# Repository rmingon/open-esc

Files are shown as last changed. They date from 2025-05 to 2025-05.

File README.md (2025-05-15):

# Open-Source 3-Phase Sensorless ESC Firmware

This is an open-source firmware for controlling 3-phase sensorless BLDC motors using an ATmega88PA microcontroller running at 8 MHz (internal oscillator).  
It is designed for small electric vehicles, drones, robotics, and DIY ESC applications.  
The design uses 6 MOSFETs in a three-phase bridge configuration and includes back-EMF sensing for sensorless commutation.

---

## Features

- Sensorless 6-step (trapezoidal) commutation
- Automatic open-loop startup
- Zero-cross detection via ADC ISR
- Hardware timer-based phase PWM with dead-time
- RC PWM input for speed control
- Optional serial interface (UART) for speed setting
- Direction control and braking support
- Dead-time insertion to prevent MOSFET shoot-through
- Auto-calibrated ADC thresholds for zero-cross detection

---

## Schematic Overview

The system includes the following main blocks:

### Microcontroller

- **ATmega88PA**, powered at 5V using AMS1117-3.3 regulator from +BATT
- Internal 8 MHz oscillator (no external crystal)
- Key pins used:
  - `PD2` → PWM input (from RC receiver)
  - `PD3/PD4/PD5` → High-side MOSFET gates (AH, BH, CH)
  - `PB0/PB1/PB2` → Low-side PWM outputs (AL, BL, CL)
  - `PC0/PC1/PC2` → ADC inputs for Phase A/B/C sensing (A0, A1, A2)

### Power Stage

- 3-phase half-bridge using 6 MOSFETs (Q1–Q6)
- High-side: A03401A
- Low-side: IRLML0030
- Gate resistors to control switching speed and prevent ringing

### Back-EMF Sensing

- Analog divider + DC blocking on each motor phase
- Inputs go to `A0`, `A1`, and `A2`
- Used for zero-cross detection in closed-loop mode

### PWM Input

- Connected to `D2` for RC signal input (standard 1–2 ms pulses)
- Used to control speed and direction
- Interrupt-based decoding for accurate readings

### Serial Debug (optional)

- Via UART (TX/RX, `PD0`/`PD1`)
- Can be used to override speed or monitor state

---

## How to Use

### 1. Assemble the Hardware

- Follow the schematic to build the ESC on a PCB or breadboard
- Ensure proper power filtering (C2, C3–C6)
- Use heatsinks or airflow on the MOSFETs if under heavy load

### 2. Upload Firmware

- Connect AVR ISP programmer to the 6-pin header
- Use [AVRDude](https://www.nongnu.org/avrdude/) or the Arduino IDE
- Ensure fuse bits are set for:
  - Internal 8 MHz clock
  - No clock division
- Upload the `.ino` firmware file

### 3. Calibrate Zero-Crossing (Auto)

- When powered, the firmware automatically calibrates ADC offset thresholds
- Ensure the motor is disconnected or not rotating for accurate calibration

### 4. Run

- Connect an RC receiver or PWM generator to `D2`
- Pulse width controls speed and direction:
  - `< 1480 µs` = reverse
  - `1480–1520 µs` = brake
  - `> 1520 µs` = forward
- Motor will spin up in open-loop mode and switch to sensorless control

### 5. Serial Control (Optional)

- Connect USB-to-serial to TX/RX
- Open serial monitor at `115200 baud`
- Send a value from `0–255` to manually set the speed (for testing/debug)

---

## Motor Braking and Reverse

- Controlled by PWM signal:
  - Brake mode: both high and low sides turned off briefly
  - Reverse: same commutation order but in reverse
- No position feedback required

---

## Dead-Time Handling

- Implemented in software by carefully disabling/enabling high/low MOSFETs with a short delay (a few µs)
- Prevents simultaneous conduction and shoot-through

---

## Files Included

- `ESC_Firmware.ino` – Full firmware with PWM control, ISR ADC, RC interface
- `README.md` – Project documentation
- Schematic (`.png`) – Visual hardware design

---

## Supported Microcontrollers

- ATmega88PA (default)
- Can be ported to ATmega328P with minimal changes

---

## Test Points

- TP1–TP3: Phase voltages for probing/debug
- TP6: PWM input
- TP5: GND
- TP4: +BATT

---

## Pictures

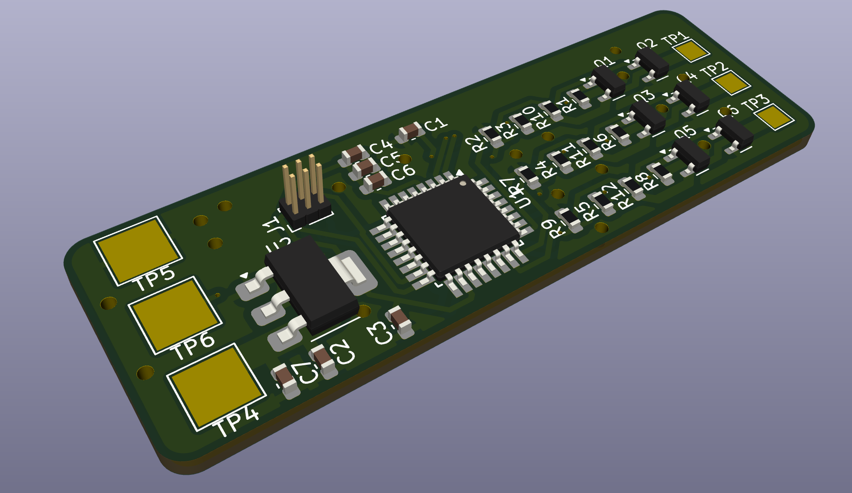
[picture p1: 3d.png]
3d

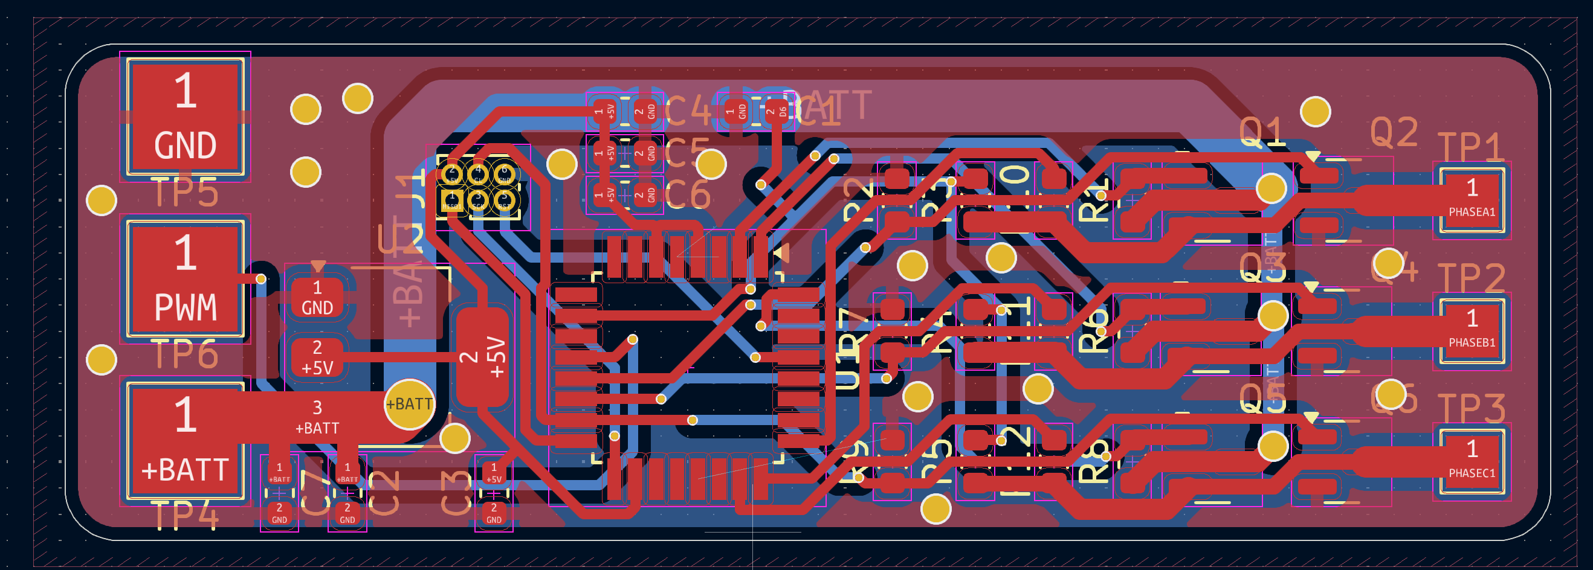
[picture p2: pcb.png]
pcb

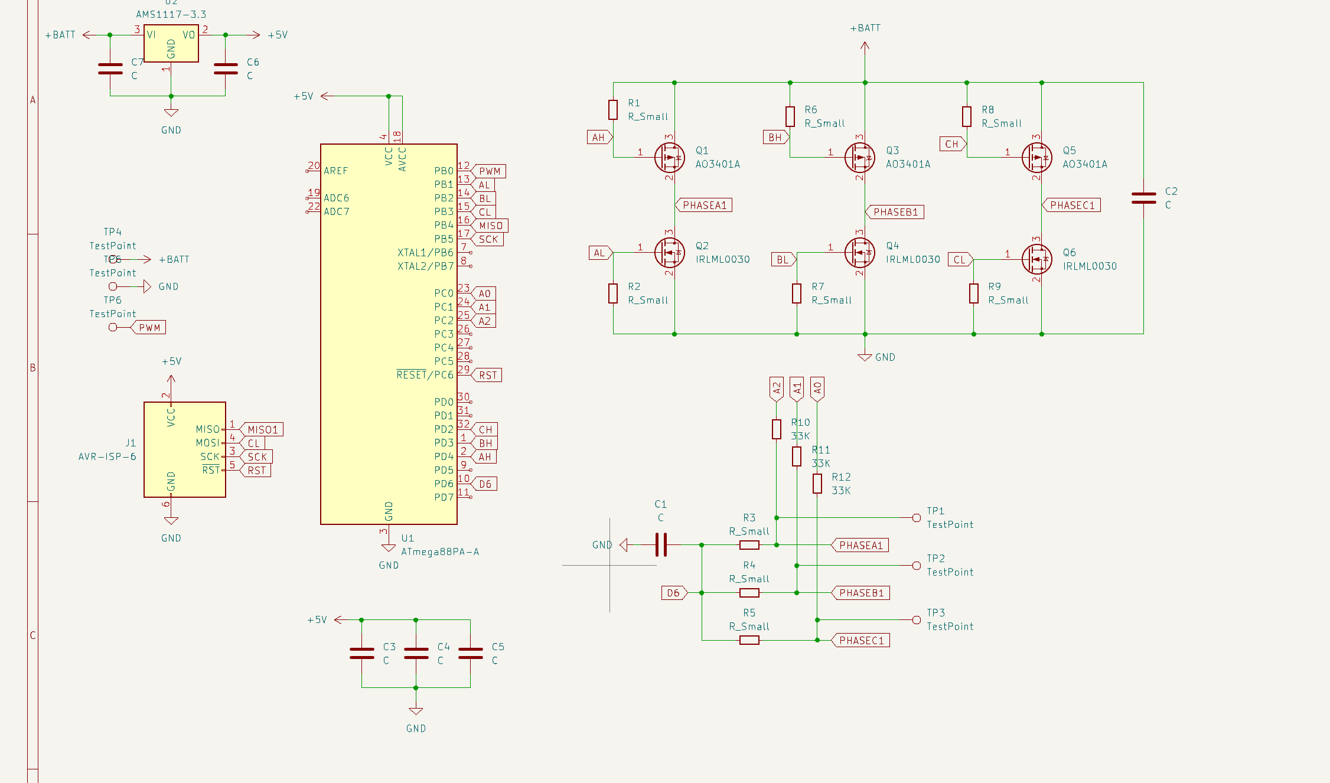
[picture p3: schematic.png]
schematic


---

## Safety Notes

- Always test with low-voltage supply first
- Double-check gate drive signals with oscilloscope
- Use overcurrent and overtemperature protection externally if needed

---

## License

MIT License — You can freely use, modify, and distribute this project.

---

## Author

Created by [Your Name / GitHub Handle]  
Feel free to fork, improve, and contribute via pull requests!

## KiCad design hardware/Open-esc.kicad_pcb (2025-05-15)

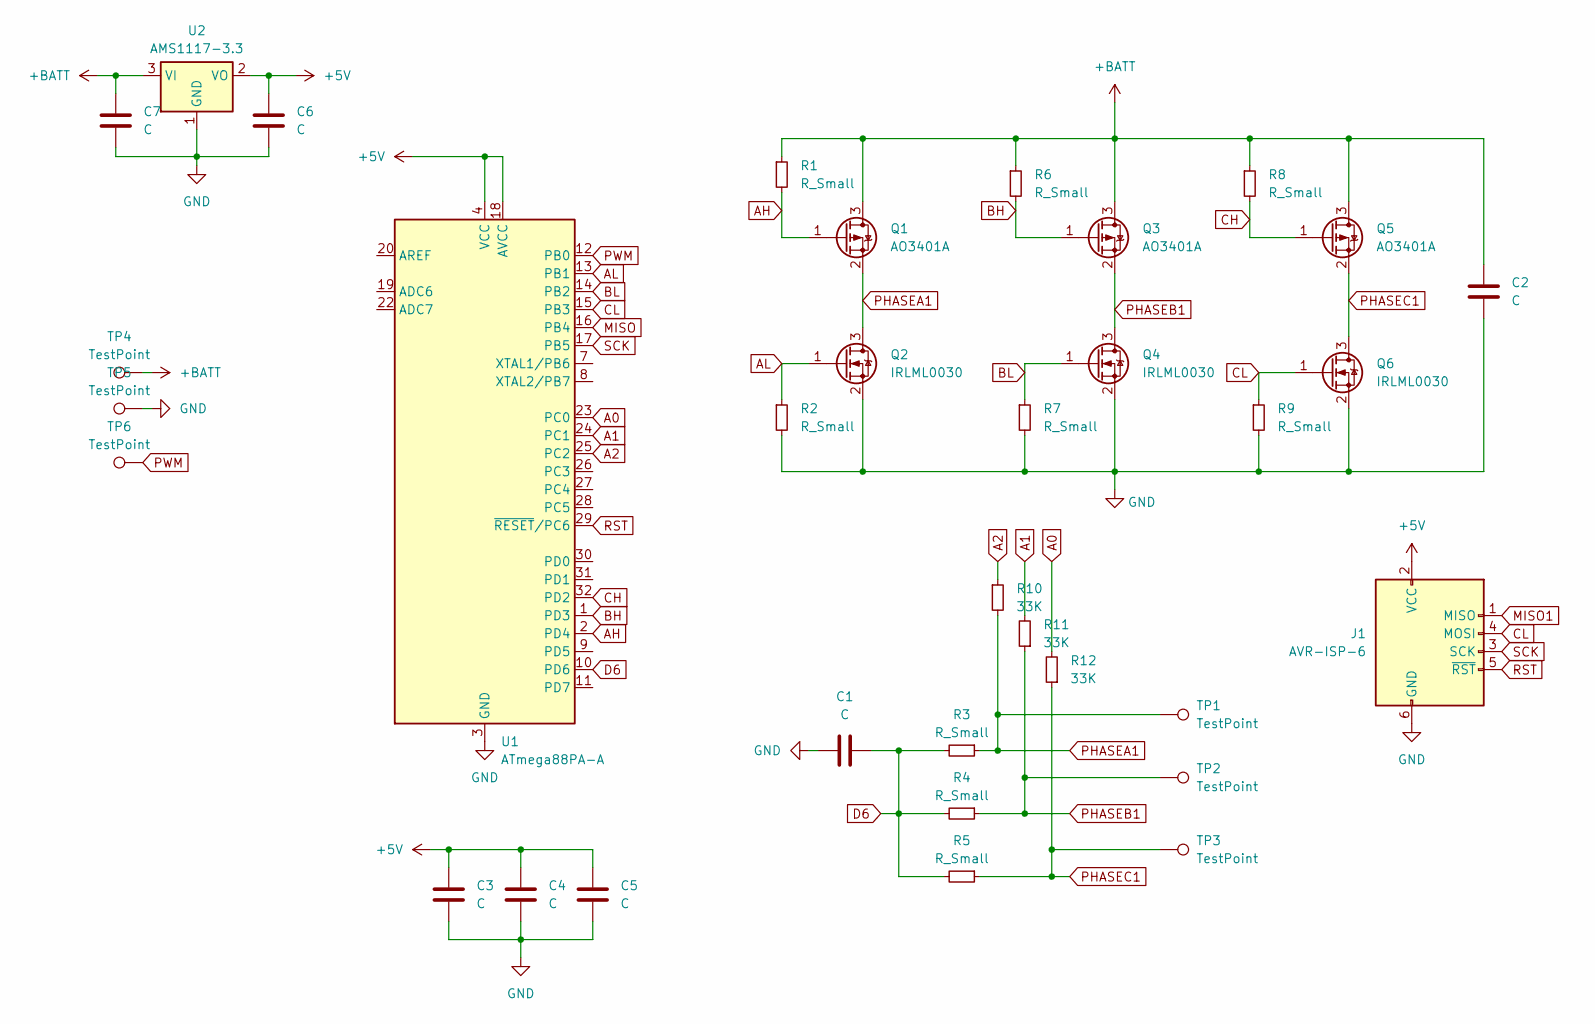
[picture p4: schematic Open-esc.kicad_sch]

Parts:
C1, C2, C3, C4, C5, C6, C7: C; C_0603_1608Metric
J1: AVR-ISP-6; PinHeader_2x03_P1.00mm_Vertical
Q1, Q3, Q5: AO3401A; SOT-23
Q2, Q4, Q6: IRLML0030; SOT-23
R1, R2, R3, R4, R5, R6, R7, R8, R9: R_Small; R_0603_1608Metric
R10, R11, R12: 33K; R_0603_1608Metric
TP1, TP2, TP3: TestPoint; TestPoint_Pad_2.0x2.0mm
TP4, TP5, TP6: TestPoint; TestPoint_Pad_4.0x4.0mm
U1: ATmega88PA-A; TQFP-32_7x7mm_P0.8mm
U2: AMS1117-3.3; SOT-223-3_TabPin2

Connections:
+5V: C3.1, C4.1, C5.1, C6.1, J1.2 (VCC), U1.4 (VCC), U1.6 (VCC), U1.18 (AVCC), U2.2 (VO)
+BATT: C2.1, C7.1, Q1.3 (D), Q3.3 (D), Q5.3 (D), R1.1, R6.1, R8.1, TP4.1, U2.3 (VI)
A0: R12.2, U1.23 (PC0)
A1: R11.2, U1.24 (PC1)
A2: R10.1, U1.25 (PC2)
AH: Q1.1 (G), R1.2, U1.2 (PD4)
AL: Q2.1 (G), R2.1, U1.13 (PB1)
BH: Q3.1 (G), R6.2, U1.1 (PD3)
BL: Q4.1 (G), R7.1, U1.14 (PB2)
CH: Q5.1 (G), R8.2, U1.32 (PD2)
CL: J1.4 (MOSI), Q6.1 (G), R9.1, U1.15 (PB3)
D6: C1.2, R3.2, R4.2, R5.2, U1.10 (PD6)
GND: C1.1, C2.2, C3.2, C4.2, C5.2, C6.2, C7.2, J1.6 (GND), Q2.2 (S), Q4.2 (S), Q6.2 (S), R2.2, R7.2, R9.2, TP5.1, U1.3 (GND), U1.5 (GND), U1.21 (GND), U2.1 (GND)
MISO: U1.16 (PB4)
MISO1: J1.1 (MISO)
PHASEA1: Q1.2 (S), Q2.3 (D), R3.1, R10.2, TP1.1
PHASEB1: Q3.2 (S), Q4.3 (D), R4.1, R11.1, TP2.1
PHASEC1: Q5.2 (S), Q6.3 (D), R5.1, R12.1, TP3.1
PWM: TP6.1, U1.12 (PB0)
RST: J1.5 (~RST), U1.29 (~RESET/PC6)
SCK: J1.3 (SCK), U1.17 (PB5)

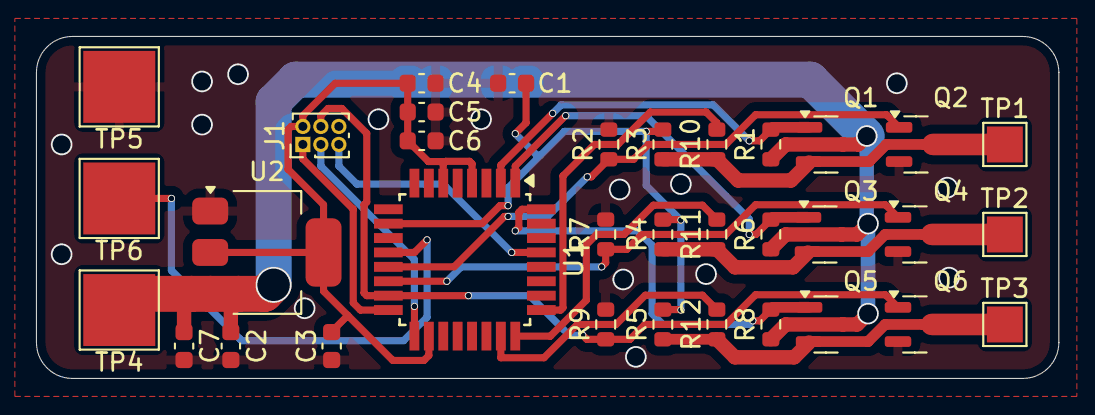
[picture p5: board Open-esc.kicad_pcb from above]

Board: 2 copper layers, 56.8 x 19.0 mm, 34 parts (0 on the bottom side), 19 nets.

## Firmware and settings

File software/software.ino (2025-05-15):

#define AH_PIN 8
#define BH_PIN 7
#define CH_PIN 6

#define AL_PIN 9
#define BL_PIN 10
#define CL_PIN 11

#define PHASE_A_ADC A2
#define PHASE_B_ADC A1
#define PHASE_C_ADC A0

#define PWM_INPUT_PIN 2  // RC-style PWM input (1–2 ms pulse)

const int8_t commutation_table[6][3] = {
  {1, 0, -1}, {1, -1, 0}, {0, 1, -1},
  {-1, 1, 0}, {0, -1, 1}, {-1, 0, 1}
};

volatile uint8_t step = 0;
volatile bool closedLoop = false;
volatile uint16_t dutyCycle = 0;
volatile uint16_t targetDutyCycle = 128;
volatile unsigned long lastStepTime = 0;
volatile unsigned int commutationDelay = 2000;
volatile bool zeroCrossDetected = false;
volatile int16_t lastADCValue = 512;
int8_t direction = 1;

uint16_t zeroCrossThresholdA = 512;
uint16_t zeroCrossThresholdB = 512;
uint16_t zeroCrossThresholdC = 512;
bool calibrationDone = false;

volatile unsigned long pwmRiseTime = 0;
volatile uint16_t pwmPulseWidth = 1500;

char inputBuffer[10];
uint8_t inputIndex = 0;

void setup() {
  Serial.begin(115200);
  Serial.println("ESC Starting...");

  // Set pin modes
  pinMode(AH_PIN, OUTPUT); digitalWrite(AH_PIN, LOW);
  pinMode(BH_PIN, OUTPUT); digitalWrite(BH_PIN, LOW);
  pinMode(CH_PIN, OUTPUT); digitalWrite(CH_PIN, LOW);

  pinMode(AL_PIN, OUTPUT); digitalWrite(AL_PIN, LOW);
  pinMode(BL_PIN, OUTPUT); digitalWrite(BL_PIN, LOW);
  pinMode(CL_PIN, OUTPUT); digitalWrite(CL_PIN, LOW);

  pinMode(PWM_INPUT_PIN, INPUT);
  attachInterrupt(digitalPinToInterrupt(PWM_INPUT_PIN), pwmISR, CHANGE);

  setupTimer1PWM();
  setupADC();
  calibrateZeroCrossThresholds();

  lastStepTime = micros();
}

void loop() {
  handlePWMAction();
  handleSerial();

  if (!closedLoop) {
    openLoopStartup();
  } else {
    if (zeroCrossDetected) {
      zeroCrossDetected = false;
      commutateStep();
    }
  }
}

// === INTERRUPT-BASED PWM INPUT ===
void pwmISR() {
  if (digitalRead(PWM_INPUT_PIN) == HIGH) {
    pwmRiseTime = micros();
  } else {
    unsigned long now = micros();
    pwmPulseWidth = now - pwmRiseTime;
  }
}

// === HANDLE RC INPUT TO SET SPEED/DIRECTION ===
void handlePWMAction() {
  if (pwmPulseWidth > 1520) {
    direction = 1;
    targetDutyCycle = map(pwmPulseWidth, 1520, 2000, 0, 255);
  } else if (pwmPulseWidth < 1480) {
    direction = -1;
    targetDutyCycle = map(pwmPulseWidth, 1000, 1480, 255, 0);
  } else {
    direction = 0;
    targetDutyCycle = 0;
    brakeMotor();
  }
}

// === BRAKING ===
void brakeMotor() {
  disableAllOutputs();
  digitalWrite(AL_PIN, HIGH);
  digitalWrite(BL_PIN, HIGH);
  digitalWrite(CL_PIN, HIGH);
}

void setupTimer1PWM() {
  TCCR1A = (1 << COM1A1) | (1 << COM1B1) | (1 << WGM10); // Fast PWM 8-bit
  TCCR1B = (1 << WGM12) | (1 << CS11);                  // prescaler 8
  OCR1A = 0;
  OCR1B = 0;
}

void setupADC() {
  ADMUX = (1 << REFS0) | (PHASE_C_ADC & 0x07);
  ADCSRA = (1 << ADEN) | (1 << ADATE) | (1 << ADIE) | (1 << ADSC)
         | (1 << ADPS2) | (1 << ADPS1) | (1 << ADPS0);
  sei();
}

void calibrateZeroCrossThresholds() {
  Serial.println("Calibrating...");
  zeroCrossThresholdA = calibrateADCPhase(PHASE_A_ADC);
  zeroCrossThresholdB = calibrateADCPhase(PHASE_B_ADC);
  zeroCrossThresholdC = calibrateADCPhase(PHASE_C_ADC);
  calibrationDone = true;
  Serial.println("Calibration complete.");
}

uint16_t calibrateADCPhase(uint8_t channel) {
  uint32_t sum = 0;
  for (uint8_t i = 0; i < 50; i++) {
    ADMUX = (ADMUX & 0xF8) | (channel & 0x07);
    delay(2);
    ADCSRA |= (1 << ADSC);
    while (ADCSRA & (1 << ADSC));
    sum += ADC;
  }
  return sum / 50;
}

void openLoopStartup() {
  unsigned long now = micros();
  if (now - lastStepTime >= commutationDelay) {
    commutateStep();
    lastStepTime = now;

    if (commutationDelay > 800) commutationDelay -= 5;
    if (dutyCycle < targetDutyCycle) dutyCycle++;

    OCR1A = dutyCycle;
    OCR1B = dutyCycle;

    if (commutationDelay <= 800) {
      closedLoop = true;
      Serial.println("Entering closed-loop mode");
    }
  }
}

void commutateStep() {
  step = (step + direction + 6) % 6;

  int8_t a = commutation_table[step][0];
  int8_t b = commutation_table[step][1];
  int8_t c = commutation_table[step][2];

  disableAllOutputs();
  delayMicroseconds(5); // Dead-time

  OCR1A = (a == -1) ? dutyCycle : 0;
  OCR1B = (b == -1) ? dutyCycle : 0;
  digitalWrite(CL_PIN, (c == -1) ? HIGH : LOW);

  digitalWrite(AH_PIN, (a == 1) ? HIGH : LOW);
  digitalWrite(BH_PIN, (b == 1) ? HIGH : LOW);
  digitalWrite(CH_PIN, (c == 1) ? HIGH : LOW);
}

void disableAllOutputs() {
  digitalWrite(AH_PIN, LOW);
  digitalWrite(BH_PIN, LOW);
  digitalWrite(CH_PIN, LOW);
  OCR1A = 0;
  OCR1B = 0;
  digitalWrite(CL_PIN, LOW);
}

void handleSerial() {
  while (Serial.available()) {
    char c = Serial.read();
    if (c == '\n' || c == '\r') {
      inputBuffer[inputIndex] = 0;
      int val = atoi(inputBuffer);
      if (val >= 0 && val <= 255) {
        targetDutyCycle = val;
        Serial.print("Set duty: ");
        Serial.println(val);
      }
      inputIndex = 0;
    } else {
      if (inputIndex < sizeof(inputBuffer) - 1) {
        inputBuffer[inputIndex++] = c;
      }
    }
  }
}

// zc detection
ISR(ADC_vect) {
  static uint8_t currentPhase = 0;
  int16_t adcVal = ADC;
  if (!calibrationDone) return;

  uint16_t threshold = 512;
  uint8_t sense = getFloatingPhaseADC(step);
  switch (sense) {
    case PHASE_A_ADC: threshold = zeroCrossThresholdA; break;
    case PHASE_B_ADC: threshold = zeroCrossThresholdB; break;
    case PHASE_C_ADC: threshold = zeroCrossThresholdC; break;
  }

  if ((lastADCValue < threshold && adcVal >= threshold) ||
      (lastADCValue > threshold && adcVal <= threshold)) {
    zeroCrossDetected = true;
  }

  lastADCValue = adcVal;
  ADMUX = (ADMUX & 0xF8) | (sense & 0x07);
}

uint8_t getFloatingPhaseADC(uint8_t s) {
  switch (s) {
    case 0: return PHASE_C_ADC;
    case 1: return PHASE_B_ADC;
    case 2: return PHASE_A_ADC;
    case 3: return PHASE_C_ADC;
    case 4: return PHASE_B_ADC;
    case 5: return PHASE_A_ADC;
    default: return PHASE_A_ADC;
  }
}

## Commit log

2025-05-14 add schematic
    [Open-esc.kicad_pcb, Open-esc.kicad_sch]
2025-05-14 wiring phase
    [Open-esc.kicad_pcb, Open-esc.kicad_sch]
2025-05-15 rename connection and add pad wiring
    [Open-esc.kicad_pcb, Open-esc.kicad_sch]
2025-05-15 add general gnd
    [Open-esc.kicad_pcb]
2025-05-17 update rst pin
    [Open-esc.kicad_sch]
